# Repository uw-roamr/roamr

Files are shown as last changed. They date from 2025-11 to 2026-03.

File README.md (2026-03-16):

# ROAMR: Really Opensource Autonomous Mobile Robot

Mobile phones and mobile robots have many common requirements:

- performant sensors (cameras, IMUs, LiDAR, GPS) and sensor fusion
- networking capabilities (WiFi, Bluetooth Low Energy, LTE)
- energy efficiency

What if we turned the iPhone into a robot?

## Architecture

### iOS host app:

- exposes the core sensor data through iOS APIs
    - Camera
    - LiDAR (iPhone Pro 12+)
    - IMU
- runs WASM bytecode using statically compiled WAMR iwasm
- communicates with ESP32 over BLE to control motors

### WASM module:

- imports read sensor functions from iOS host
- multi-threaded application with autonomy logic
- compiled using WASI-SDK and threading
    - C++: https://github.com/WebAssembly/wasi-sdk

### ESP32:

- recieves commands over BLE and uses SimpleFOC to control motors

## Setup

```sh
pip install pre-commit
pre-commit
```

## Run App with Robot
- Open/build iOS app.
- Connect to bluetooth using the app
- Drive robot!

### Optional:
- Open HTML page in webpage folder.
- Run websocket on the websocket page of the app
- Connect to app websocket
- Drive robot!

## Development

See [WASM/README.md](WASM/README.md)

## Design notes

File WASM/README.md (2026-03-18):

# WASM Runtime

This directory is the robot runtime that gets compiled to `slam_main.wasm` and hosted by the iOS app through WAMR. The best entrypoint for understanding the system is [WASM/slam_main.cpp](/Users/thomasonzhou/src/roamr/WASM/slam_main.cpp). A mirrored copy also exists at [iOS/roamr/WASM/slam_main.cpp](/Users/thomasonzhou/src/roamr/iOS/roamr/WASM/slam_main.cpp), but the code in this directory should be treated as the source of truth.

Build `slam_main.wasm` from [WASM/build_wasm.sh](/Users/thomasonzhou/src/roamr/WASM/build_wasm.sh):

```sh
cd WASM
./build_wasm.sh
```

The script currently compiles:

- `slam_main.cpp`
- `core/telemetry.cpp`
- `mapping/map.cpp`
- `mapping/map_update.cpp`
- `mapping/visualization.cpp`
- `planning/frontier_explorer.cpp`
- `planning/frontier_simplified.cpp`
- `planning/planner_bridge.cpp`
- `sensors/imu_calibration.cpp`
- `sensors/imu_preintegration.cpp`

Target details:

- `wasm32-wasip1-threads`
- shared memory enabled
- exceptions and RTTI disabled
- output: `slam_main.wasm`

If recording is enabled, the current recorder writes a simple session layout:

```text
session-<timestamp>/
  imu.csv
  pose.csv
  images/
    frame-000001-<timestamp>-<width>x<height>x3.rgb
  points/
    frame-000001-<timestamp>.ply
```

`imu.csv` stores timestamped accelerometer and gyroscope samples. `pose.csv`
stores timestamped predicted poses. Camera images are written as raw RGB with
dimensions encoded in the filename, and point clouds are written as binary PLY
files with per-point RGB colors.

## Host Boundary

The WASM module does not own devices directly. It talks to the iOS host through imported functions and a small exported API.

Imported from the host:

- IMU reads
- LiDAR + camera frame reads
- wheel odometry reads
- motor writes
- telemetry / text logging

Exported to the host:

- `set_planner_goal_map_pixel`
- `clear_planner_goal_map_pixel`

Those exports let the UI set or clear a manual planning target on the rendered map.

## Native ML Bridge

The iOS host now includes a generic model bridge for dynamically loaded perception
models. The intended bundle layout is:

```text
<bundle-dir>/
  stop_sign_main.wasm
  stop_sign_bundle/
    manifest.json
    model.pte
```

Build ML-focused entrypoints with [WASM/build_ml_wasm.sh](/Users/kai/code/roamr/WASM/build_ml_wasm.sh):

```sh
cd WASM
./build_ml_wasm.sh
./build_ml_wasm.sh stop_sign_main.cpp
```

`stop_sign_main.cpp` shows the guest-side pattern:

1. call `ml::open_model("stop_sign_bundle/manifest.json", ...)`
2. poll `ml::run_latest_camera_frame(...)`
3. inspect detections
4. call `write_motors(...)` when policy conditions are met

The manifest contract currently expects:

- `task = "object_detection"`
- `backend = "executorch"`
- first output tensor flattened as rows of 6 floats:
  `class_id, score, x_min, y_min, x_max, y_max`
- RGB input only
- `resize_mode = "stretch"`

See [WASM/ml/model.h](/Users/kai/code/roamr/WASM/ml/model.h),
[WASM/stop_sign_main.cpp](/Users/kai/code/roamr/WASM/stop_sign_main.cpp),
and [WASM/stop_sign_bundle/manifest.json](/Users/kai/code/roamr/WASM/stop_sign_bundle/manifest.json).

## Runtime Overview

`main()` starts seven long-lived threads:

| Thread | Purpose |
| --- | --- |
| `autonomy_thread` | waits for readiness, runs the initial scan, services scan requests |
| `imu_thread` | calibrates IMU biases, integrates orientation, updates the IMU side of `g_pose` |
| `lidar_camera_thread` | reads LiDAR/camera frames into a queued slot buffer and samples pose history for each frame |
| `mapping_thread` | consumes queued LiDAR frames, updates the occupancy map, publishes snapshots and map deltas |
| `planner_thread` | wakes on map/goal changes, computes overlays and world paths |
| `telemetry_thread` | renders map frames plus pose/path/frontier overlays for the host |
| `control_thread` | reads wheel odometry, maintains the shared pose, follows planned paths, drives motors |

This split matters:

- mapping no longer renders the final map image
- planning no longer runs inside the mapping loop
- LiDAR is no longer a two-slot latest-frame handoff

## State Machine

There are two layers of runtime state:

- `g_state`: coarse lifecycle state
- `g_autonomy_substate`: finer autonomy/debug state from [WASM/autonomy/autonomy.h](/Users/thomasonzhou/src/roamr/WASM/autonomy/autonomy.h)

Top-level lifecycle:

```text
SENSOR_INIT -> AUTONOMY_INIT -> AUTONOMY_ENGAGED
```

### `SENSOR_INIT`

The autonomy thread waits for:

- IMU calibration to complete
- at least one non-empty LiDAR frame
- wheel odometry readiness when the selected pose mode depends on wheel odom

### `AUTONOMY_INIT`

The runtime waits for the first real map update, then performs an initial closed-loop `scan_4x90()` if scanning is enabled.

That scan:

- rotates in four quarter-turn segments
- uses wheel/pose feedback, not a blind timed turn
- stops and settles after each segment
- exists to seed the initial occupancy map before normal autonomy begins

### `AUTONOMY_ENGAGED`

Once engaged:

- the planner reacts to map and goal updates
- the control loop follows the latest world-frame path
- failed planning can request another scan
- reaching a goal also requests another scan so new free space can be exposed

Autonomy substates include:

- `PLANNER_INIT`: waiting for planner to initialize from the initial map after scanning 4x90
- `WAITING_FOR_PATH`: planner started and is drawing paths
- `FRONTIER_DETECTION`
- `GOAL_SELECTION`
- `PLANNING_GOAL`
- `FOLLOWING_PATH`
- `NO_PATH_AVAILABLE`
- `SCAN_REQUESTED`
- `SCANNING`: 4x90 loop to refresh local map

## Shared Data Flow

The runtime is built around a few published handoff points rather than one giant loop.

### Pose

`g_pose` is the shared robot pose. It is protected by `m_pose`, and a short pose history buffer is also maintained so LiDAR frames can be associated with a pose near their timestamp.

Current compile-time pose mode in [WASM/slam_main.cpp](/Users/thomasonzhou/src/roamr/WASM/slam_main.cpp) is `fused_IMU_wheel_odom`:

- wheel odometry provides translation
- IMU integration provides the current heading quaternion

That is still a lightweight fusion path, not a full estimator. The code comments correctly note that raw IMU preintegration drifts and should not be treated as a final long-term orientation solution.

### LiDAR / Camera Queue

LiDAR frames move through a four-slot queue:

- slot states: `FREE`, `WRITING`, `QUEUED`, `READING`
- producer: `lidar_camera_thread`
- consumer: `mapping_thread`

For each frame, the producer:

1. claims a free slot
2. reads host LiDAR/camera data
3. converts points into FLU
4. samples pose history at the frame timestamp
5. queues the slot for mapping

This is a real queued producer/consumer pipeline, not the older "latest frame wins" double buffer.

### Mapping Publication

The mapping thread consumes queued LiDAR frames, filters/transforms points, and updates `mapping::Map`.

Each successful update publishes:

- a monotonic `g_map_update_revision`
- `g_latest_map_snapshot`
- `g_latest_map_state`
- a `MapDeltaEvent` with newly occupied cells for the planner

That delta queue is what lets planning skip unnecessary replans when the new obstacle evidence does not intersect the current path corridor.

### Planning Publication

The planner thread wakes on:

- goal changes
- map revisions
- queued map deltas

It reads the latest published snapshot, updates a `PlanningOverlay`, and caches the world-frame path exposed through `planning::bridge::copy_latest_plan_world(...)`.

Two planning modes exist:

- manual goal mode: a UI pixel is converted to a map cell and planned directly
- automatic frontier mode: when no manual goal is active, the planner searches for reachable frontiers

The current bridge logic in [WASM/planning/planner_bridge.cpp](/Users/thomasonzhou/src/roamr/WASM/planning/planner_bridge.cpp):

- keeps a D* Lite planner for direct goal planning
- rate-limits automatic frontier replans
- caches frontier goal candidates across replans
- invalidates the current plan when the controller reaches the goal

### Telemetry

The telemetry thread renders the published map snapshot plus:

- pose trail
- planned path
- frontier candidates
- selected frontier cluster / seed

Rendering happens in [WASM/mapping/visualization.h](/Users/thomasonzhou/src/roamr/WASM/mapping/visualization.h) and its `.cpp`, separate from occupancy integration.

## Subsystem Notes

### Sensors

- [WASM/sensors/calibration.h](/Users/thomasonzhou/src/roamr/WASM/sensors/calibration.h) and [WASM/sensors/imu_calibration.cpp](/Users/thomasonzhou/src/roamr/WASM/sensors/imu_calibration.cpp) handle stillness-based IMU bias estimation and recalibration.
- [WASM/sensors/imu_preintegration.h](/Users/thomasonzhou/src/roamr/WASM/sensors/imu_preintegration.h) and `.cpp` integrate IMU orientation.
- [WASM/sensors/lidar_camera.h](/Users/thomasonzhou/src/roamr/WASM/sensors/lidar_camera.h) defines the host frame payload and point-frame conversion helpers.
- [WASM/sensors/wheel_odometry.h](/Users/thomasonzhou/src/roamr/WASM/sensors/wheel_odometry.h) handles differential-drive odometry integration and wheel-speed estimation.

### Mapping

- [WASM/mapping/map.cpp](/Users/thomasonzhou/src/roamr/WASM/mapping/map.cpp) owns the occupancy grid.
- [WASM/mapping/map_update.h](/Users/thomasonzhou/src/roamr/WASM/mapping/map_update.h) and `.cpp` translate LiDAR frames into map updates and snapshots.
- [WASM/mapping/map_snapshot.h](/Users/thomasonzhou/src/roamr/WASM/mapping/map_snapshot.h) is the planner/telemetry handoff format.
- [WASM/mapping/costmap.h](/Users/thomasonzhou/src/roamr/WASM/mapping/costmap.h) builds the inflated navigation costmap used by planning.

### Planning

- [WASM/planning/planner.h](/Users/thomasonzhou/src/roamr/WASM/planning/planner.h) provides grid planning utilities.
- [WASM/planning/frontier_explorer.cpp](/Users/thomasonzhou/src/roamr/WASM/planning/frontier_explorer.cpp) implements reachable-frontier selection.
- [WASM/planning/planner_bridge.h](/Users/thomasonzhou/src/roamr/WASM/planning/planner_bridge.h) and `.cpp` are the thread boundary between mapping/control/UI.

### Controls

- [WASM/controls/motors.h](/Users/thomasonzhou/src/roamr/WASM/controls/motors.h) converts twist commands to wheel commands and writes motors through the host.
- [WASM/controls/path_following.h](/Users/thomasonzhou/src/roamr/WASM/controls/path_following.h) tracks the published world path and produces velocity commands.

## Current Behavior Summary

If you want the shortest accurate mental model for `slam_main.cpp`, it is this:

1. Bring up IMU, LiDAR, and wheel odometry.
2. Publish a shared pose and short pose history.
3. Queue LiDAR frames with timestamp-matched poses into the mapper.
4. Publish map snapshots and occupancy deltas.
5. Replan only when the map, goal, or current path validity actually changes.
6. Follow the current world path until the goal is reached or planning fails.
7. Trigger another scan when exploration stalls or a goal completes.

## Historical Notes

[WASM/implementation_notes.md](/Users/thomasonzhou/src/roamr/WASM/implementation_notes.md) is still useful for context, but it should be read as design history rather than the current runtime contract. When that file and `slam_main.cpp` disagree, trust `slam_main.cpp`.

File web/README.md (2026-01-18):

# ROAMR Video Streaming

This directory contains the web interface for viewing the live video stream from your ROAMR robot.

## Quick Start

### 1. Start the WebSocket Server on iPhone

1. Open the ROAMR app on your iPhone
2. Navigate to the **WebSocket** tab (bottom navigation)
3. Tap the **Play** button to start the server
4. Note the IP address displayed (e.g., `192.168.1.5`)

### 2. Start Video Streaming

1. Navigate to the **AR View** tab
2. Tap the **Play** button to start the AR session
3. Tap the **Start Stream** button to begin video streaming
   - Button will turn red and say "Stop Stream" when active
   - Video frames are automatically encoded and sent via WebSocket

### 3. View the Stream

1. Open `video-stream.html` in any web browser (Chrome, Safari, Firefox, etc.)
2. Enter the WebSocket URL: `ws://[YOUR_IP]:8080` (e.g., `ws://192.168.1.5:8080`)
3. Click **Connect**
4. You should see the live video stream from your iPhone camera!

## Features

### Video Stream Viewer

- **Real-time video streaming** at 720p, 30 FPS
- **Live statistics**: FPS counter, frame count, and frame size
- **Connection log**: View connection events and debugging info
- **Responsive design**: Works on desktop and mobile browsers
- **Keyboard shortcut**: Press Enter in the URL field to connect

### iOS App Controls

- **Start/Stop Streaming**: Toggle video streaming on/off
- **Quality**: Currently set to 720p at 60% JPEG quality
  - Adjust in `LiDARManager.swift:30` if needed
- **Frame Rate**: 30 FPS (configurable)

## Technical Details

### Architecture

```
iPhone Camera (ARKit)
    ↓
VideoStreamManager (captures & encodes to JPEG)
    ↓
WebSocketServerManager (broadcasts binary data)
    ↓
WebSocket (port 8080)
    ↓
Web Browser (video-stream.html)
```

### Performance

- **Resolution**: 1280x720 (720p)
- **Frame Rate**: ~30 FPS
- **Compression**: JPEG at 60% quality
- **Bandwidth**: ~1-2 Mbps (depends on scene complexity)
- **Latency**: ~100-300ms end-to-end

### Customization

To adjust video quality, edit `iOS/roamr/Managers/LiDARManager.swift`:

```swift
videoStreamManager.configure(
    arSession: session,
    targetFPS: 30,      // Frames per second
    quality: 0.6        // JPEG quality (0.0 - 1.0)
)
```

To change resolution, edit `iOS/roamr/Managers/VideoStreamManager.swift`:

```swift
private var targetWidth: Int = 1280   // Width in pixels
private var targetHeight: Int = 720   // Height in pixels
```

## Troubleshooting

### Connection Issues

- **Can't connect**: Ensure both devices are on the same WiFi network
- **Firewall**: Some networks block WebSocket connections
- **IP address**: Double-check the IP address from the iOS app

### Performance Issues

- **Low FPS**: Reduce quality or resolution in settings
- **High latency**: Check network quality, reduce bandwidth usage
- **Choppy video**: Ensure iPhone isn't overheating or low on battery

### No Video Stream

1. Ensure WebSocket server is running (green indicator)
2. Check that AR session is active (LiDAR tab)
3. Verify "Start Stream" button is pressed (should be red)
4. Check browser console for errors (F12)

## Requirements

- **iOS Device**: iPhone with ARKit support (iPhone 6s or later)
- **Network**: Both devices on same WiFi network
- **Browser**: Any modern browser (Chrome, Safari, Firefox, Edge)

## Advanced Usage

### URL Parameters

You can pre-populate the WebSocket URL using query parameters:

```
video-stream.html?ip=192.168.1.5
```

This will automatically set the URL to `ws://192.168.1.5:8080`.

### Integration with Robot Control

The video stream runs alongside the existing WebSocket functionality for robot control. You can:
- Send control commands via WebSocket (text messages)
- Receive video stream (binary frames)
- Forward commands to Bluetooth peripheral (ESP32)

All on the same WebSocket connection!

## Future Enhancements

Potential improvements:
- H.264 encoding for better compression
- WebRTC for lower latency
- Multiple video quality presets
- Recording capability
- Multi-client streaming with individual quality settings

---

**Built for ROAMR** - Really Opensource Autonomous Mobile Robot

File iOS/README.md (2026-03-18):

# iOS App

## Getting started

1. [Enable developer mode on iPhone](https://developer.apple.com/documentation/xcode/enabling-developer-mode-on-a-device)

2. Under the `Signing & Capabilities` tab in XCode, select a team (e.g. Personal Team) and enter a unique identifier.

3. Click Build.

Core components:

## ExecuTorch

The dynamic model bridge in `Managers/ModelRunner.swift` is written to use the
official ExecuTorch Swift package when it is linked into the app. Until that
package is added in Xcode, `ml_open_model` will return `runtime_unavailable`.

## How build new WAMR
- Clone WAMR (https://github.com/bytecodealliance/wasm-micro-runtime)
- Navigate to `/wasm-micro-runtime/product-mini/platforms`
- Run `generate_xcodeproj.sh`
- Open the XCode project and edit the `CMakeList.txt` file to be the same as the one provided in our repo.
- Run the `ALL_BUILD` target
- Open the header files, located at `/wasm-micro-runtime/product-mini/platforms/ios/iwasm-proj/distribution/wasm`
- Copy them to your project and include them in a header bridging file
- Copy the library (.a file) to your project, located at `/wasm-micro-runtime/product-mini/platforms/ios/iwasm-proj`
- Check this `library.a` file is added to `Link Binaries with Libraries` inside `Build Phases`
- Add the folder `library.a` lives in to `Library Search Paths` inside `Build Settings`

## WebAssembly Runner

- [WAMR: WebAssemby Micro Runtime](https://bytecodealliance.github.io/wamr.dev/)

## Sensor Access

- Managers/LiDARManager.swift

## TODO:

- Protobuf serialization/deserialization
- Connect sensors to WASM

- manage different PRODUCT_BUNDLE_IDENTIFIER under project.pbxproj

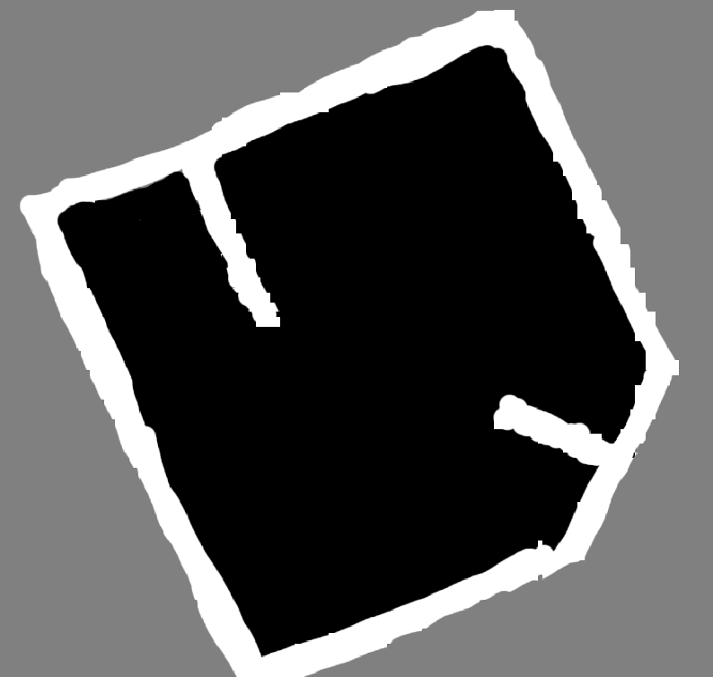
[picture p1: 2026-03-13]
tools/gt3.png

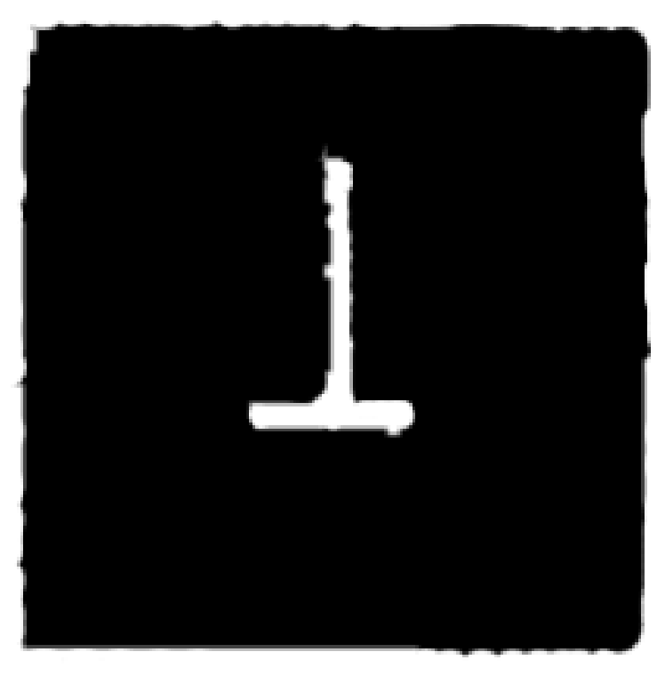
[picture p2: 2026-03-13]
tools/gt2.png

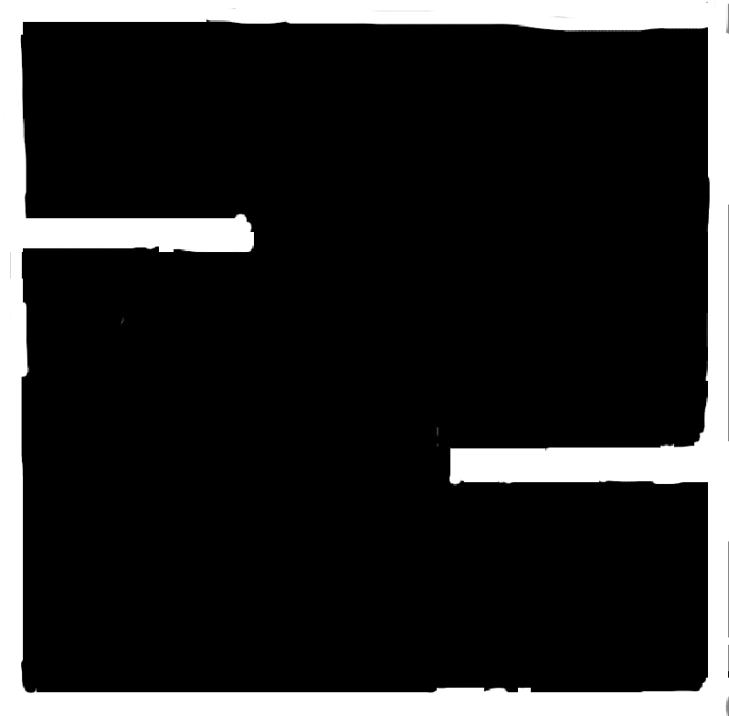
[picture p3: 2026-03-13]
tools/gt1.png

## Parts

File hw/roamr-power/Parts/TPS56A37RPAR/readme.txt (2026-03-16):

Notes:

1. All drill sizes are the maximum size provided by the manufacture (as required to calculate the minimum pad size).
2. All dimensions in building footprints are the maximum (including any tolerance) as defined by the manufacturer with the exception of row pitch (which is always nominal).  If only the normal sizing is provided we will input that dimension in mils, rounded to the nearest mil per our standards.
3. Slots are currently identified as entities describing the size of the slot (arcs, lines, etc.) on the board outline layer.  The extremities are identified with a via at each end.  These slots will either need to be:
	a. identified and dimensioned on your fabrication document
	b. or they will need to be converted to slots (assuming the targeted tool has a slot capability) using the process defined in your cad tool for identifying a padstack as a slot.
		i. Typically this is only capable of a width and length of the slot and a size of the mill radius that creates the slot.
		ii. Choosing to use the native tool slots will require removing entities on the board outline and the associated pads in the footprint.

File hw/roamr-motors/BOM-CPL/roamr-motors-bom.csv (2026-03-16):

Reference | Qty | Value | Manufacturer_Part_Number | DNP | Exclude from BOM | Exclude from Board | Footprint | Datasheet
C1,C2,C8 | 3 | 10uF |  |  |  |  | Capacitor_SMD:C_0603_1608Metric | ~
C3,C4 | 2 | 2.2uF |  |  |  |  | Capacitor_SMD:C_0603_1608Metric | ~
C5 | 1 | 4.7uF |  |  |  |  | Capacitor_SMD:C_0603_1608Metric | ~
C6,C9,C14,C17,C23,C26 | 6 | 0.1uF |  |  |  |  | Capacitor_SMD:C_0603_1608Metric | ~
C7 | 1 | 22uF |  |  |  |  | Capacitor_SMD:C_0603_1608Metric | ~
C10,C13,C16,C22,C25 | 5 | 1uF |  |  |  |  | Capacitor_SMD:C_0603_1608Metric | ~
C11,C12 | 2 | 0.1uF |  | DNP |  |  | Capacitor_SMD:C_0603_1608Metric | ~
C15,C24 | 2 | 47nF |  |  |  |  | Capacitor_SMD:C_0603_1608Metric | ~
C18,C20,C21,C27,C29,C30 | 6 | 30pF |  |  |  |  | Capacitor_SMD:C_0603_1608Metric | ~
C19,C28 | 2 | 10uF |  |  |  |  | RVT1E100M0405:RVT1E100M0405 | ~
D1,D4 | 2 | SMLJ13CA-R | SMLJ13CA-R |  |  |  | SMLJ13CA-R:DIOM7959X262N | ~
D2,D3,D5,D6,D7,D8 | 6 | LESD5D5.0CT1G | LESD5D5.0CT1G |  |  |  | LESD5D5.0CT1G:LESD5D50CT1G | ~
D9,D10 | 2 | 1N5819HW-7-F | 1N5819HW-7-F |  |  |  | 1N5819HW_7_F:SOD3715X145N
D11,D12,D17,D18 | 4 | PMEG3050EP,115 | PMEG3050EP,115 |  |  |  | PMEG3050EP:PMEG3050EP115 | https://assets.nexperia.com/documents/data-sheet/PMEG3050EP.pdf
D13,D14,D15,D16 | 4 | GLED | KT-0603G |  |  |  | KT-0603:LEDC1608X70N | ~
D19 | 1 | RLED | KT-0603R |  |  |  | KT-0603:LEDC1608X70N | ~
F1,F2 | 2 | 0466005.NRHF | 0466005.NRHF |  |  |  | 0466005:F1206 | https://lcsc.com/product-detail/Surface-Mount-Fuses_Littelfuse_0466005-NRHF_5A-32V_C57525.html
J1,J4,J5,J8 | 4 | JST_XH_S2B-XH-A-1 | JST_XH_S2B-XH-A-1 |  |  |  | Connector_JST:JST_XH_S2B-XH-A-1_1x02_P2.50mm_Horizontal | ~
J2,J3 | 2 | USB4215-03-A | USB4215-03-A |  |  |  | USB4215_03_A:CONN_8p94X6p5X3p16_12L_GCC | USB4215-03-A
J6,J9 | 2 | JST_PH_B3B-PH-SM4-TB | JST_PH_B3B-PH-SM4-TB |  |  |  | Connector_JST:JST_PH_B3B-PH-SM4-TB_1x03-1MP_P2.00mm_Vertical | ~
J7,J10 | 2 | JST_SH_BM06B-SRSS-TB | JST_SH_BM06B-SRSS-TB |  |  |  | Connector_JST:JST_SH_BM06B-SRSS-TB_1x06-1MP_P1.00mm_Vertical | ~
NT1,NT2 | 2 | NetTie_2 |  |  | Excluded from BOM |  | NetTie:NetTie-2_SMD_Pad0.5mm | ~
Q1,Q2 | 2 | L8050QLT1G | L8050QLT1G |  |  |  | L8050QLT1G:L8050QLT1G | https://datasheet.datasheetarchive.com/originals/distributors/Datasheets-28/DSA-558356.pdf
R1,R2,R3,R4 | 4 | 5.1kR |  |  |  |  | Resistor_SMD:R_0603_1608Metric | ~
R5 | 1 | 4.3kR |  |  |  |  | Resistor_SMD:R_0603_1608Metric | ~
R6 | 1 | 910R |  |  |  |  | Resistor_SMD:R_0603_1608Metric | ~
R7,R16,R17 | 3 | 0R |  |  |  |  | Resistor_SMD:R_0603_1608Metric | ~
R8,R9 | 2 | 100R |  |  |  |  | Resistor_SMD:R_0603_1608Metric | ~
R10 | 1 | 47.5k |  | DNP |  |  | Resistor_SMD:R_0603_1608Metric | ~
R11 | 1 | 1k |  |  |  |  | Resistor_SMD:R_0603_1608Metric | ~
R12,R13,R19 | 3 | 10kR |  |  |  |  | Resistor_SMD:R_0603_1608Metric | ~
R14 | 1 | 22.1k |  |  |  |  | Resistor_SMD:R_0603_1608Metric | ~
R15 | 1 | 47.5k |  |  |  |  | Resistor_SMD:R_0603_1608Metric | ~
R18 | 1 | 430R |  |  |  |  | Resistor_SMD:R_0603_1608Metric | ~
R20,R21,R22,R23,R24,R25 | 6 | 1kR |  |  |  |  | Resistor_SMD:R_0603_1608Metric | ~
SW1,SW2 | 2 | 1825910-6 | 1825910-6 |  |  |  | 1825910_6:SW4_1825910-B_TEC | 1825910-6
TP1,TP2,TP3,TP4,TP6,TP7,TP8,TP9,TP10,TP11,TP12 | 11 | TestPoint |  |  |  |  | TestPoint:TestPoint_Pad_D1.5mm | ~
TP5 | 1 | TestPoint | 5005-5009 |  |  |  | TestPoint:TestPoint_Keystone_5005-5009_Compact | ~
U1 | 1 | SGM2212-3.3XKC3G_TR | SGM2212-3.3XKC3G/TR |  |  |  | SGM2212-3.3XKC3G_TR:SOT230P700X180-4N | http://cn.sg-micro.com/uploads/soft/20220506/1651835177.pdf
U2 | 1 | CP2102N-A02-GQFN28 | CP2102N-A02-GQFN28 |  |  |  | Package_DFN_QFN:QFN-28-1EP_5x5mm_P0.5mm_EP3.35x3.35mm | https://www.silabs.com/documents/public/data-sheets/cp2102n-datasheet.pdf
U3 | 1 | ESP32-S3-WROOM-1 | ESP32-S3-WROOM-1 |  |  |  | RF_Module:ESP32-S3-WROOM-1 | https://www.espressif.com/sites/default/files/documentation/esp32-s3-wroom-1_wroom-1u_datasheet_en.pdf
U4,U5 | 2 | DRV8316CRRGFR | DRV8316CRRGFR |  |  |  | DRV8316CRRGFR:VQFN40_RGF_TEX | https://www.ti.com/lit/gpn/drv8316c

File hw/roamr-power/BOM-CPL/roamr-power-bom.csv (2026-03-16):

Id | Designator | Footprint | Quantity | Designation | Supplier and ref
1 | D6 | DIOM7959X262N | 1 | SMLJ13A
2 | C6 | C_0805_2012Metric | 1 | 15.0uF
3 | D8,D7,D2 | LEDC1608X70N | 3 | GLED
4 | D3 | LEDC1608X70N | 1 | RLED
5 | R16,R15 | R_0603_1608Metric | 2 | 56kR
6 | J4 | USB4125GFA | 1 | USB4125-GF-A
7 | J3,J2 | JST_XH_S2B-XH-A-1_1x02_P2.50mm_Horizontal | 2 | JST_XH_S2B-XH-A-1
8 | Q1 | SOT95P240X110-3N | 1 | BSS84PH6327XTSA2
9 | U2 | SOT95P280X145-6N | 1 | TPS2553DDBVR
10 | R6 | R_0603_1608Metric | 1 | 1.3R
11 | R8,R11 | R_0603_1608Metric | 2 | 510R
12 | R10,R7 | R_0603_1608Metric | 2 | 910R
13 | C9,C7 | C_0603_1608Metric | 2 | 4.7uF
14 | R12,R13 | R_0603_1608Metric | 2 | 10kR
15 | SW2,SW1 | OS102011MA1QN1 | 2 | OS102011MS2QN1
16 | C1,C14,C13 | C_0603_1608Metric | 3 | 0.1uF
17 | L2 | IND_VLS6045EX-4R7M_TDK | 1 | 4.7uH
18 | L1 | IND_PCC-M0645M_PAN-L | 1 | 3.3uH
19 | U1 | RPA0010A-MFG | 1 | TPS56A37RPAR
20 | C5 | C_0603_1608Metric | 1 | 1.0uF
21 | C10,C4 | C_0603_1608Metric | 2 | 22.0uF
22 | C8,C11 | 16SVF270M | 2 | 39.0uF
23 | D1,D5,D4 | PMEG3050EP115 | 3 | PMEG3050EP,115
24 | J1 | TB00250002BE | 1 | TB002-500-02BE
25 | C12 | CAPAE660X610N | 1 | 120uF
26 | R4 | R_0603_1608Metric | 1 | 10.0kR
27 | TP1,TP4,TP2 | TestPoint_Pad_D1.5mm | 3 | TestPoint
28 | R5 | R_0603_1608Metric | 1 | 4.3kR
29 | C3 | C_0603_1608Metric | 1 | 150.0pF
30 | R14 | R_0603_1608Metric | 1 | 7.5kR
31 | TP3 | TestPoint_Keystone_5005-5009_Compact | 1 | TestPoint
32 | R9 | R_0603_1608Metric | 1 | 100kR
33 | U3 | SON50P200X200X80-9N | 1 | TPS259541DSGR
34 | R2 | R_0603_1608Metric | 1 | 24kR
35 | R1 | R_0603_1608Metric | 1 | 52.3kR
36 | R3 | R_0603_1608Metric | 1 | 73.2kR

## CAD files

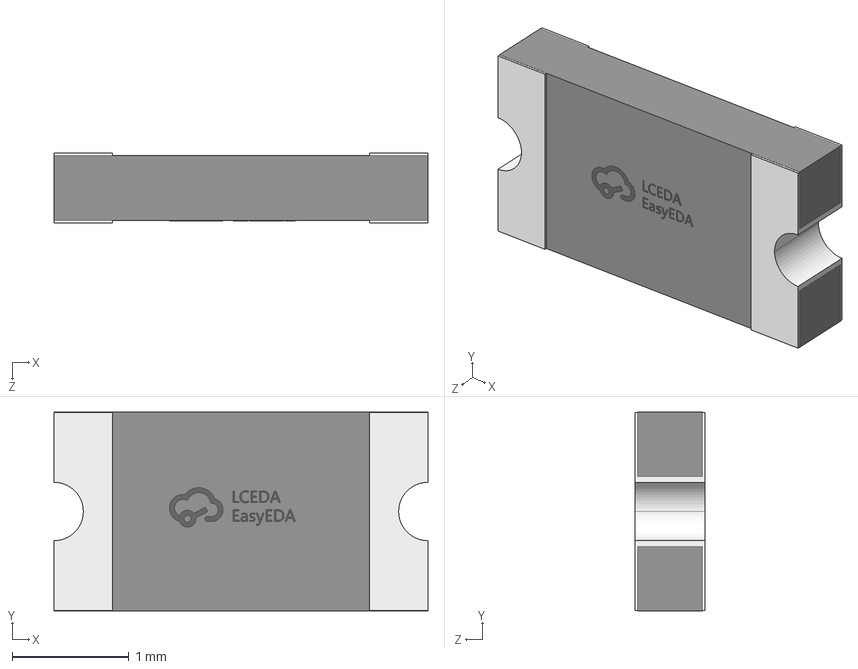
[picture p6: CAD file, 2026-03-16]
hw/roamr-motors/Parts/0466005/F1206_L3.2-W1.7-H0.6.step
3.20 x 1.70 x 0.6 mm

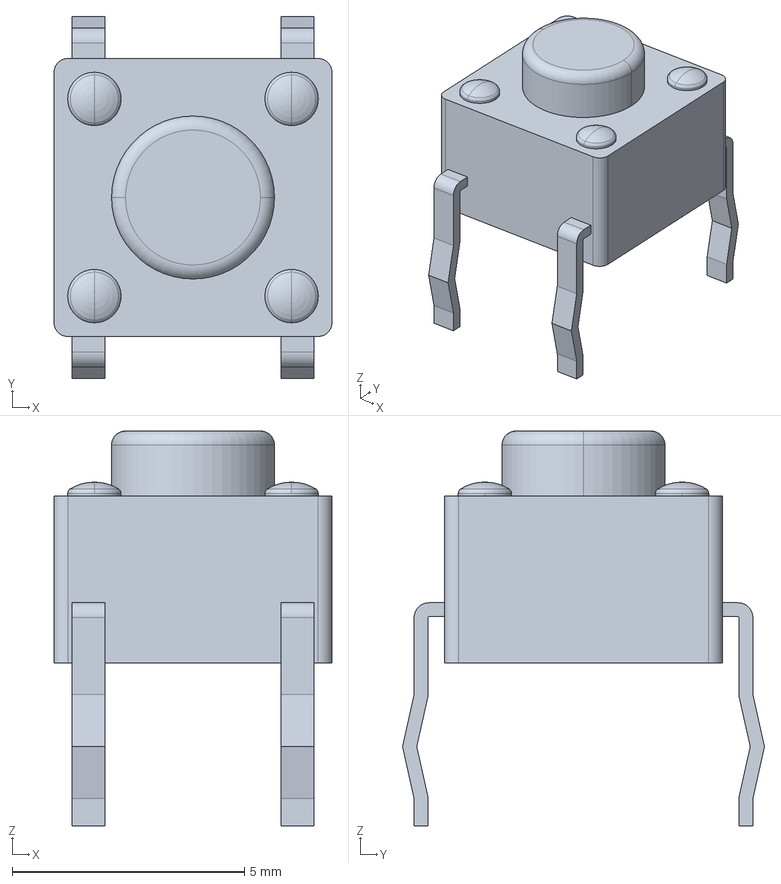
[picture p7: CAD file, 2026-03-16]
hw/roamr-motors/Parts/1825910_6/c-1825910-6-c-3d.stp
5.99 x 7.80 x 8.51 mm

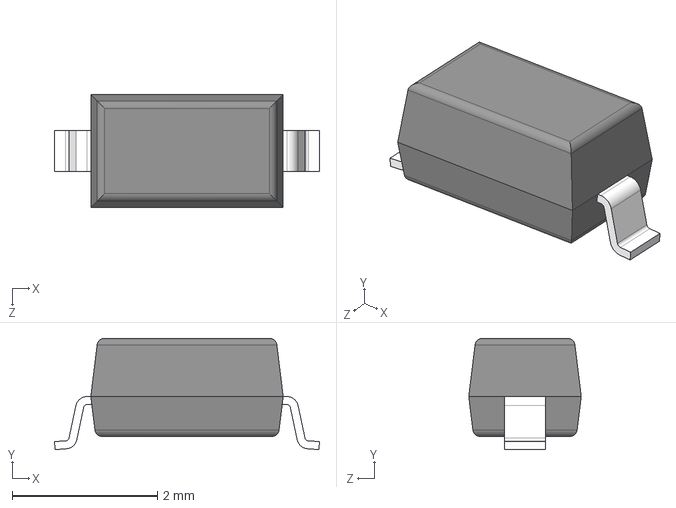
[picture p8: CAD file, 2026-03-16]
hw/roamr-motors/Parts/1N5819HW_7_F/1N5819HW-7-F.step
3.65 x 1.53 x 1.55 mm

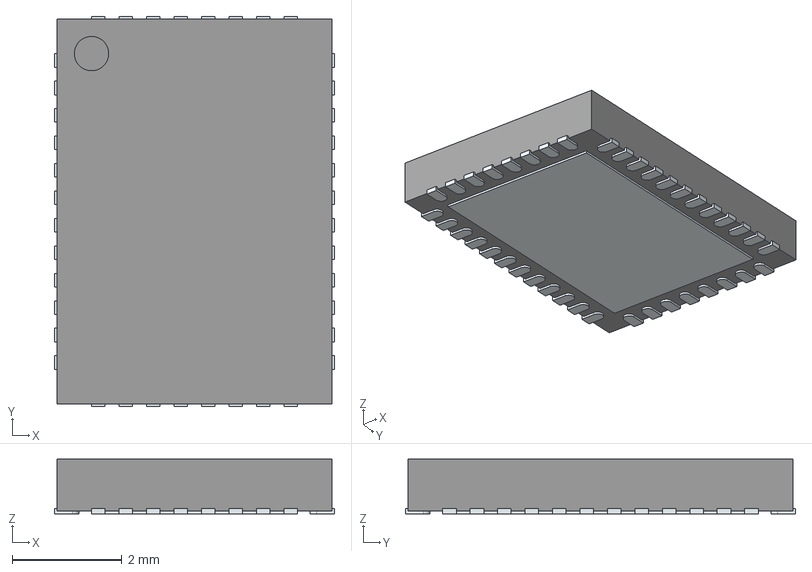
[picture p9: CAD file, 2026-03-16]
hw/roamr-motors/Parts/DRV8316CRRGFR/DRV8316CRRGFR.stp
5.10 x 7.10 x 1.00 mm
ThermalPin
PinsArrayLR
PinsArrayTB

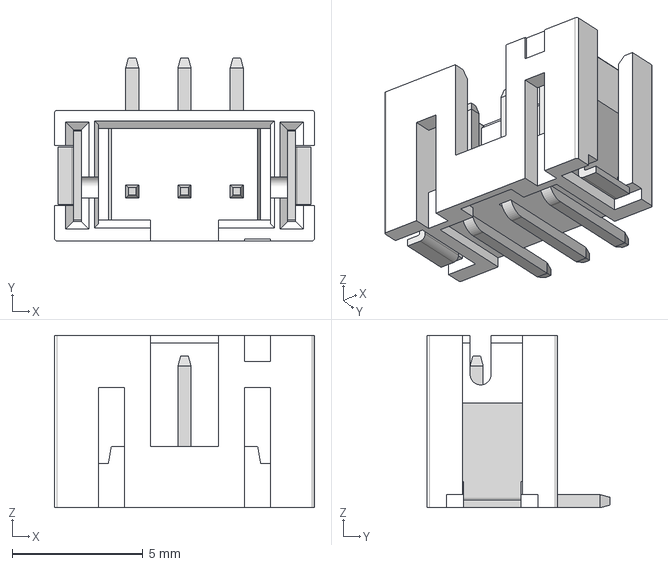
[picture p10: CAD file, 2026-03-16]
hw/roamr-motors/Parts/JST-B3B-PH-SM4-TB/B3B-PH-SM4-TB_LF__SN_.stp
9.95 x 7.00 x 6.60 mm

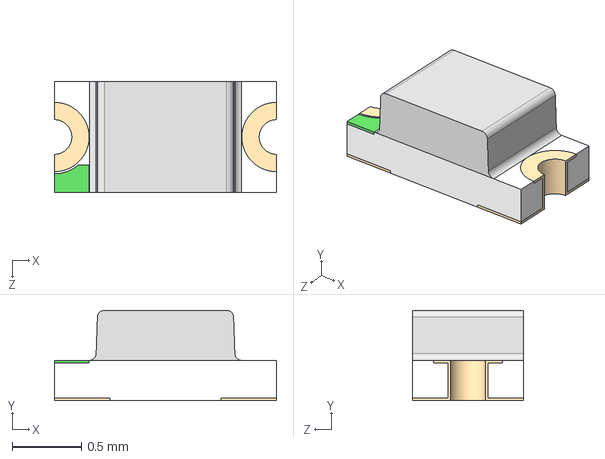
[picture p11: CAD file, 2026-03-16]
hw/roamr-motors/Parts/KT-0603/KT-0603R--3DModel-STEP-269445.STEP
1.60 x 0.65 x 0.8 mm

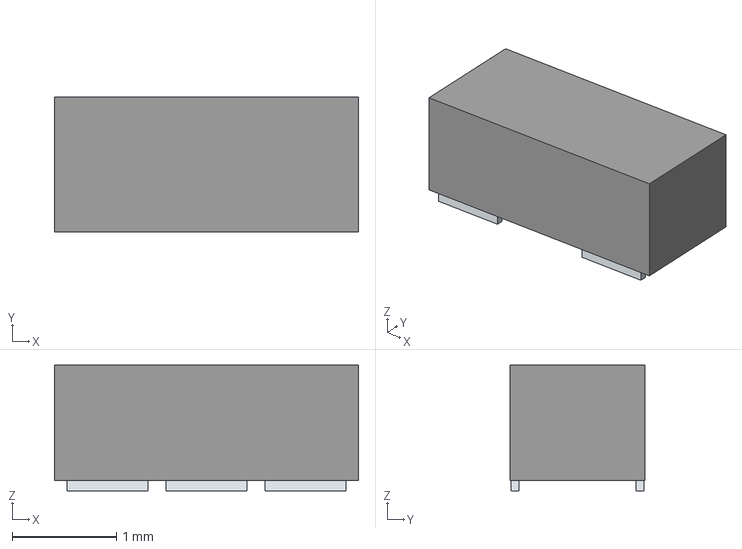
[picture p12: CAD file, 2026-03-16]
hw/roamr-motors/Parts/L8050QLT1G/L8050QLT1G.stp
2.92 x 1.30 x 1.21 mm
Pins

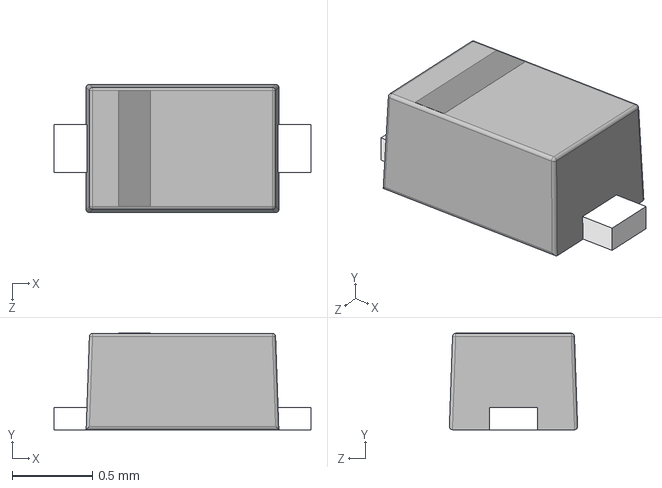
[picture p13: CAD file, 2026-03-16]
hw/roamr-motors/Parts/LESD5D5.0CT1G/LESD5D5.0CT1G.stp
1.60 x 0.601 x 0.799 mm

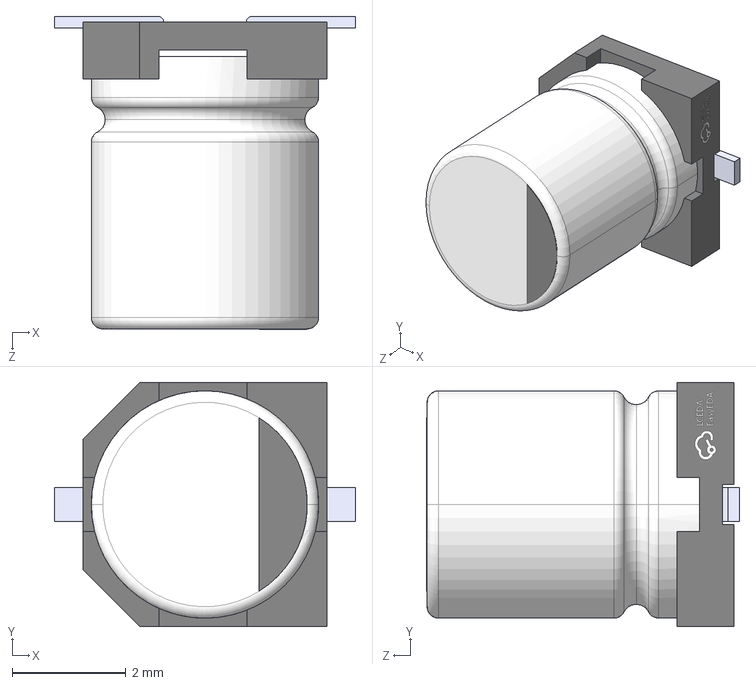
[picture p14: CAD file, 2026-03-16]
hw/roamr-motors/Parts/RVT1E100M0405/CAP-SMD_L4.3-W4.3-H5.3-LS5.1.step
5.30 x 4.30 x 5.51 mm

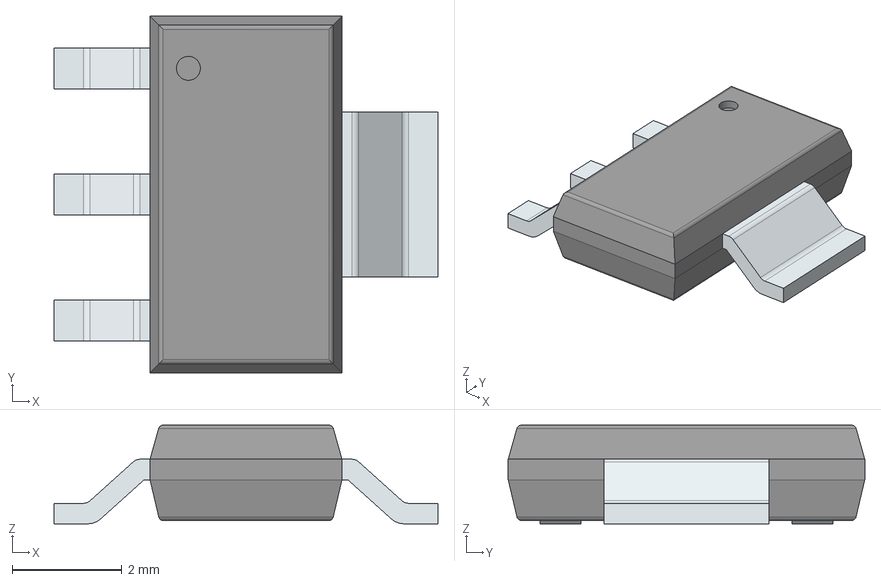
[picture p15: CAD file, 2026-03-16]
hw/roamr-motors/Parts/SGM2212-3.3XKC3G_TR/SGM2212-3.3XKC3G_TR.stp
7.00 x 6.50 x 1.80 mm
PinsArrayL
FilletPinR

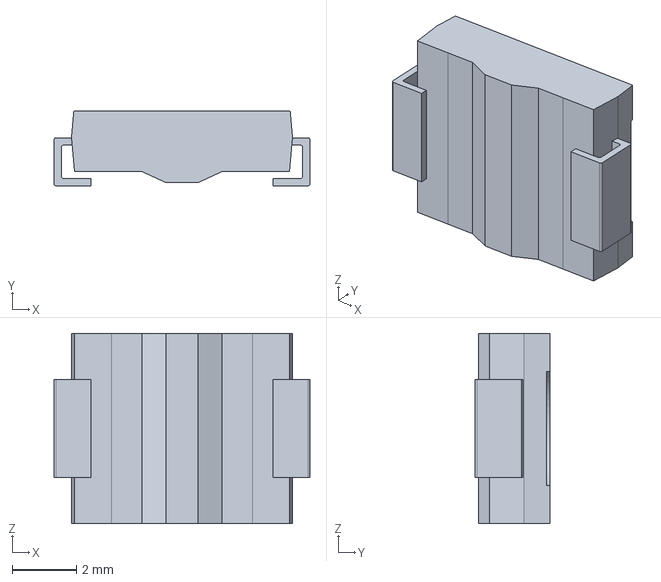
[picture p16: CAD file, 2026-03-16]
hw/roamr-motors/Parts/SMLJ13CA-R/SMLJ13CA-R.stp
7.94 x 2.31 x 5.91 mm

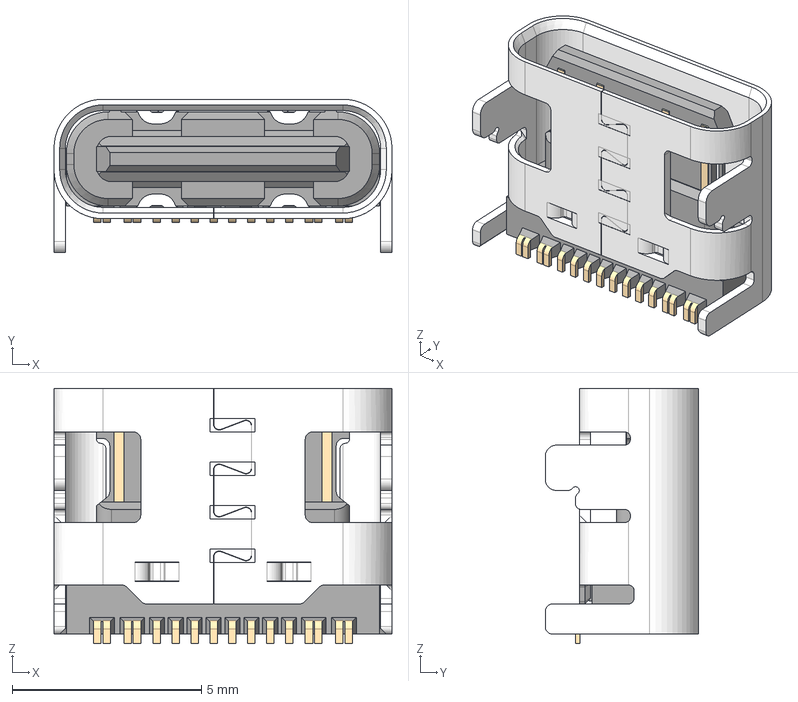
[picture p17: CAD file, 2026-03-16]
hw/roamr-motors/Parts/USB4215_03_A/USB4215-03-A.stp
8.94 x 4.06 x 6.75 mm
USB4215-03-A_PART1
USB4215-03-A_PART2

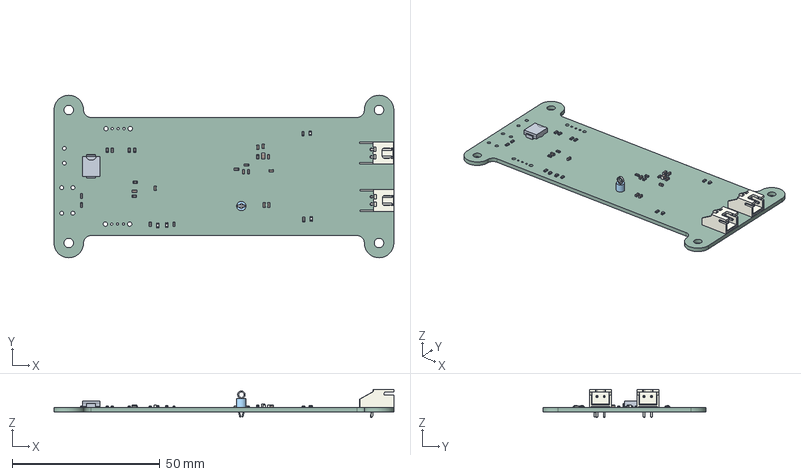
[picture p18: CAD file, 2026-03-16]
hw/roamr-power/Outputs/roamr-power.step
115.0 x 55.0 x 9.50 mm
KT-0603R--3DModel-STEP-269445 x 4
R_0603_1608Metric x 16
SMLJ13CA-R
C_0603_1608Metric x 9
JST_XH_S2B-XH-A-1_1x02_P2.50mm_Horizontal x 2
C_0805_2012Metric
TestPoint_Keystone_5005-5009_Compact
roamr-power_PCB

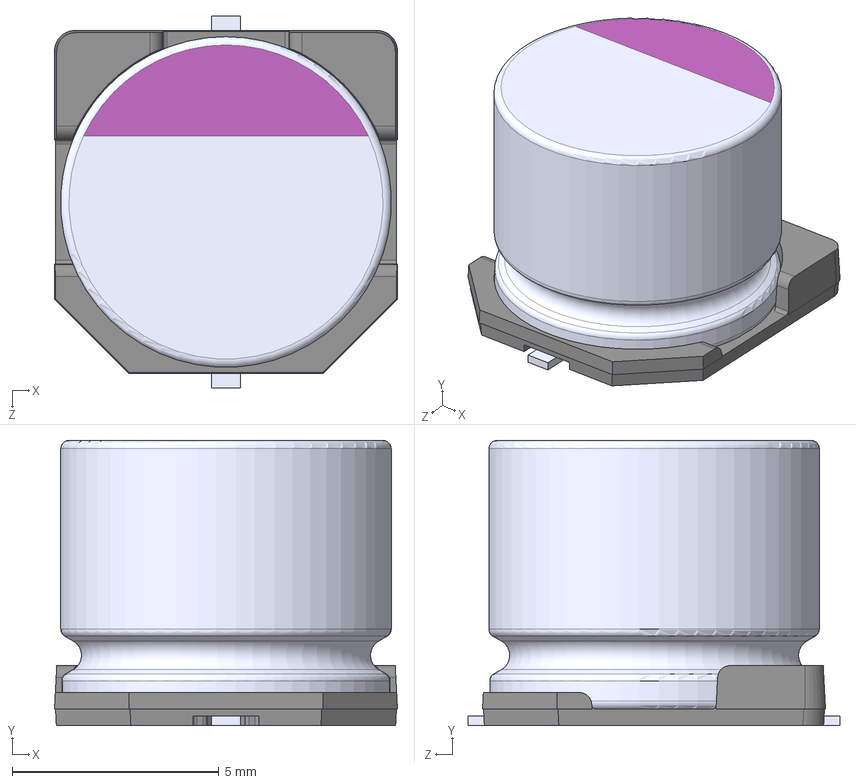
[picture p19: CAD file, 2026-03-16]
hw/roamr-power/Parts/35SVPF39M/35SVPF39M.stp
8.30 x 6.90 x 9.00 mm

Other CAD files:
hw/roamr-power/Parts/BSS84PH6327XTSA2/BSS84PH6327XTSA2.stp
hw/roamr-power/Parts/ETQ-P4M3R3YFN/ETQ-P4M3R3YFN.stp
hw/roamr-power/Parts/GYG1E121MCQ1GS/GYG1E121MCQ1GS.stp
hw/roamr-power/Parts/PMEG3050EP/PMEG3050EP,115.stp
hw/roamr-power/Parts/OS102011MS2QN1/OS102011MS2QN1.stp
hw/roamr-power/Parts/TB002-500-02BE/TB002-500-02BE.stp
hw/roamr-power/Parts/TPS2553DDBVR/TPS2553DDBVR.stp
hw/roamr-power/Parts/TPS259541DSGR/TPS259541DSGR.stp
hw/roamr-power/Parts/TPS56A37RPAR/TPS56A37RPAR.stp
hw/roamr-power/Parts/USB4125-GF-A/USB4125-GF-A.stp
hw/roamr-power/Parts/VLS6045EX_4R7M/VLS6045EX-4R7M.stp

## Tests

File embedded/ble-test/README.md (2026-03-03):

| Supported Targets | ESP32 | ESP32-C2 | ESP32-C3 | ESP32-C5 | ESP32-C6 | ESP32-C61 | ESP32-H2 | ESP32-H21 | ESP32-P4 | ESP32-S2 | ESP32-S3 |
| --- | ----- | --- | --- | --- | --- | --- | --- | --- | --- | --- | --- |

# BLE Test Example

This folder structure was derived from the [esp-idf](https://github.com/espressif/esp-idf) 'blink' example.

This provides a demo which advertises the esp32 as "ESP32C6". You can download the nrfConnect app on your phone to connect to the device and upload data. Currently, the device only supports receiving and printing strings.

## How to Use Example

Before project configuration and build, be sure to set the correct chip target using `idf.py set-target <chip_name>`. If using vscode, you can also set the target in the bottom bar where you see a chip symbol.

### Hardware Required

* A development board with BLE compatibility (e.g. ESP32-C6-DevKitC etc.)
* A USB cable for Power supply and programming

See [Development Boards](https://www.espressif.com/en/products/devkits) for more information about it.

### Configure the Project

Open the project configuration menu (`idf.py menuconfig`). Or you can click the gear symbol in the bottom menu of vscode.

Make sure to select BLE 4.2 and disable BLE 5.

### Build and Flash

Run `idf.py -p PORT flash monitor` to build, flash and monitor the project. Or, you can click the wrench icon to build the project, then the lightning icon to flash the project.

(To exit the serial monitor, type ``Ctrl-]``.)

See the [Getting Started Guide](https://docs.espressif.com/projects/esp-idf/en/latest/get-started/index.html) for full steps to configure and use ESP-IDF to build projects.

### Monitor the Output

Run `idf.py monitor` to monitor the project. Or, you can the TV icon to monitor the serial output from the ESP32.

## SimpleFOC

SimpleFOC and SimpleFOC drivers are cloned into components.

Setup details (clone commands + required component `CMakeLists.txt` files):
[`SIMPLEFOC_COMPONENTS_SETUP.md`](SIMPLEFOC_COMPONENTS_SETUP.md)

# SimpleFOC Components Setup

This project expects `simplefoc` and `simplefoc_drivers` as local ESP-IDF components under `components/`.

## 1. Clone Repositories

From the project root:

```bash
mkdir -p components
git clone https://github.com/simplefoc/Arduino-FOC.git components/simplefoc
git clone https://github.com/simplefoc/Arduino-FOC-drivers.git components/simplefoc_drivers
```

Optional: pin to known-good revisions:

```bash
git -C components/simplefoc checkout 395b6cd4c621fe460c1d61a99bc0fc38913d5481
git -C components/simplefoc_drivers checkout ed05aa1644de36cbd19f43e8ea5c3edb643cefa9
```

## 2. Add `CMakeLists.txt` Files

Upstream repos do not include ESP-IDF component registration files, so create them.

### `components/simplefoc/CMakeLists.txt`

```cmake
file(GLOB_RECURSE SOURCES "src/*.cpp" "src/*.c")

idf_component_register(SRCS ${SOURCES}
                       INCLUDE_DIRS "src"
                       REQUIRES espressif__arduino-esp32)

target_compile_options(${COMPONENT_LIB} PRIVATE
                       -Wno-error=uninitialized
                       -Wno-error=overloaded-virtual
                       -Wno-error=switch
                       -Wno-error=comment)
```

### `components/simplefoc_drivers/CMakeLists.txt`

```cmake
file(GLOB_RECURSE SOURCES "src/*.cpp" "src/*.c")

idf_component_register(SRCS ${SOURCES}
                       INCLUDE_DIRS "src"
                       REQUIRES espressif__arduino-esp32 simplefoc)

target_compile_options(${COMPONENT_LIB} PRIVATE
                       -Wno-error=overloaded-virtual
                       -Wno-error=switch
                       -Wno-error=comment)
```

## 3. Confirm Main Component Dependencies

Ensure [`main/CMakeLists.txt`](main/CMakeLists.txt) includes:

- `REQUIRES ... simplefoc ... simplefoc_drivers`

Then build:

```bash
idf.py build
```

## BLE Odometry Upload Protocol

The firmware exposes one custom service (`0x00FF`) with 2 characteristics:

- `0xFF01` control (`WRITE`, `WRITE_NO_RSP`)
- `0xFF02` data (`NOTIFY`)

### Control commands (`FF01`)

- `SET_PERIOD <sample_period_ms>`
- `CLEAR` (clears pending encoder backlog)

Legacy motor command writes (`"<left> <right> <duration>"`) still work on `FF01` and can be sent continuously while odometry notifications are active.

### Data frames (`FF02` notify)

Each notification is MTU-aware and chunked (`max_payload = ATT_MTU - 3`).

- Header:
- `seq`: `uint16` little-endian
- `n`: `uint8` sample count
- Payload:
- `n` samples, each sample:
- `dl_ticks`: `int16` little-endian
- `dr_ticks`: `int16` little-endian

So frame size is `3 + 4*n` bytes.

There is no separate status characteristic in the stripped-down firmware.
### Status payload (`FF03` read, little-endian)

- `state`: `uint8` (`0=IDLE, 1=RECORDING, 2=UPLOADING`)
- `buffered_samples`: `uint16`
- `dropped_samples`: `uint16`
- `last_seq`: `uint16` (`0xFFFF` before first upload frame)
- `sample_period_ms`: `uint16`

### docker build

For reproducible builds across platforms, we suggest using the docker container for release-v5.5

https://docs.espressif.com/projects/esp-idf/en/stable/esp32/api-guides/tools/idf-docker-image.html

```sh
docker run --rm -v $PWD:/project -w /project -u $UID -e HOME=/tmp -it espressif/idf:release-v5.5
```

## Linux
```sh
docker run --rm -v $PWD:/project -w /project -u $UID -e HOME=/tmp -it --device=/dev/ttyUSB0 --group-add dialout espressif/idf:release-v5.5
```

Build, then flash the firmware.

```sh
idf.py build
```

Then flash the ESP. It may be necessary to configure additional settings in Windows or MacOS.

```sh
idf.py flash
```

## Windows Instructions:

Run the following command in a separate terminal to open the COM port to the ESP (check your COM port in device manager)
```sh
esp_rfc2217_server -v -p 4000 COM3
```
To flash the ESP,  run the following command in roamr/embedded/ble-test
```sh
MSYS_NO_PATHCONV=1 docker run --rm -v "/$(pwd):/project" -w /project -u $UID -e HOME=/tmp -it espressif/idf:release-v5.5 idf.py --port 'rfc2217://host.docker.internal:4000?ign_set_control' flash
```

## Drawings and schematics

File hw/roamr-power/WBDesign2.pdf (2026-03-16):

## WEBENCH ® Design Report

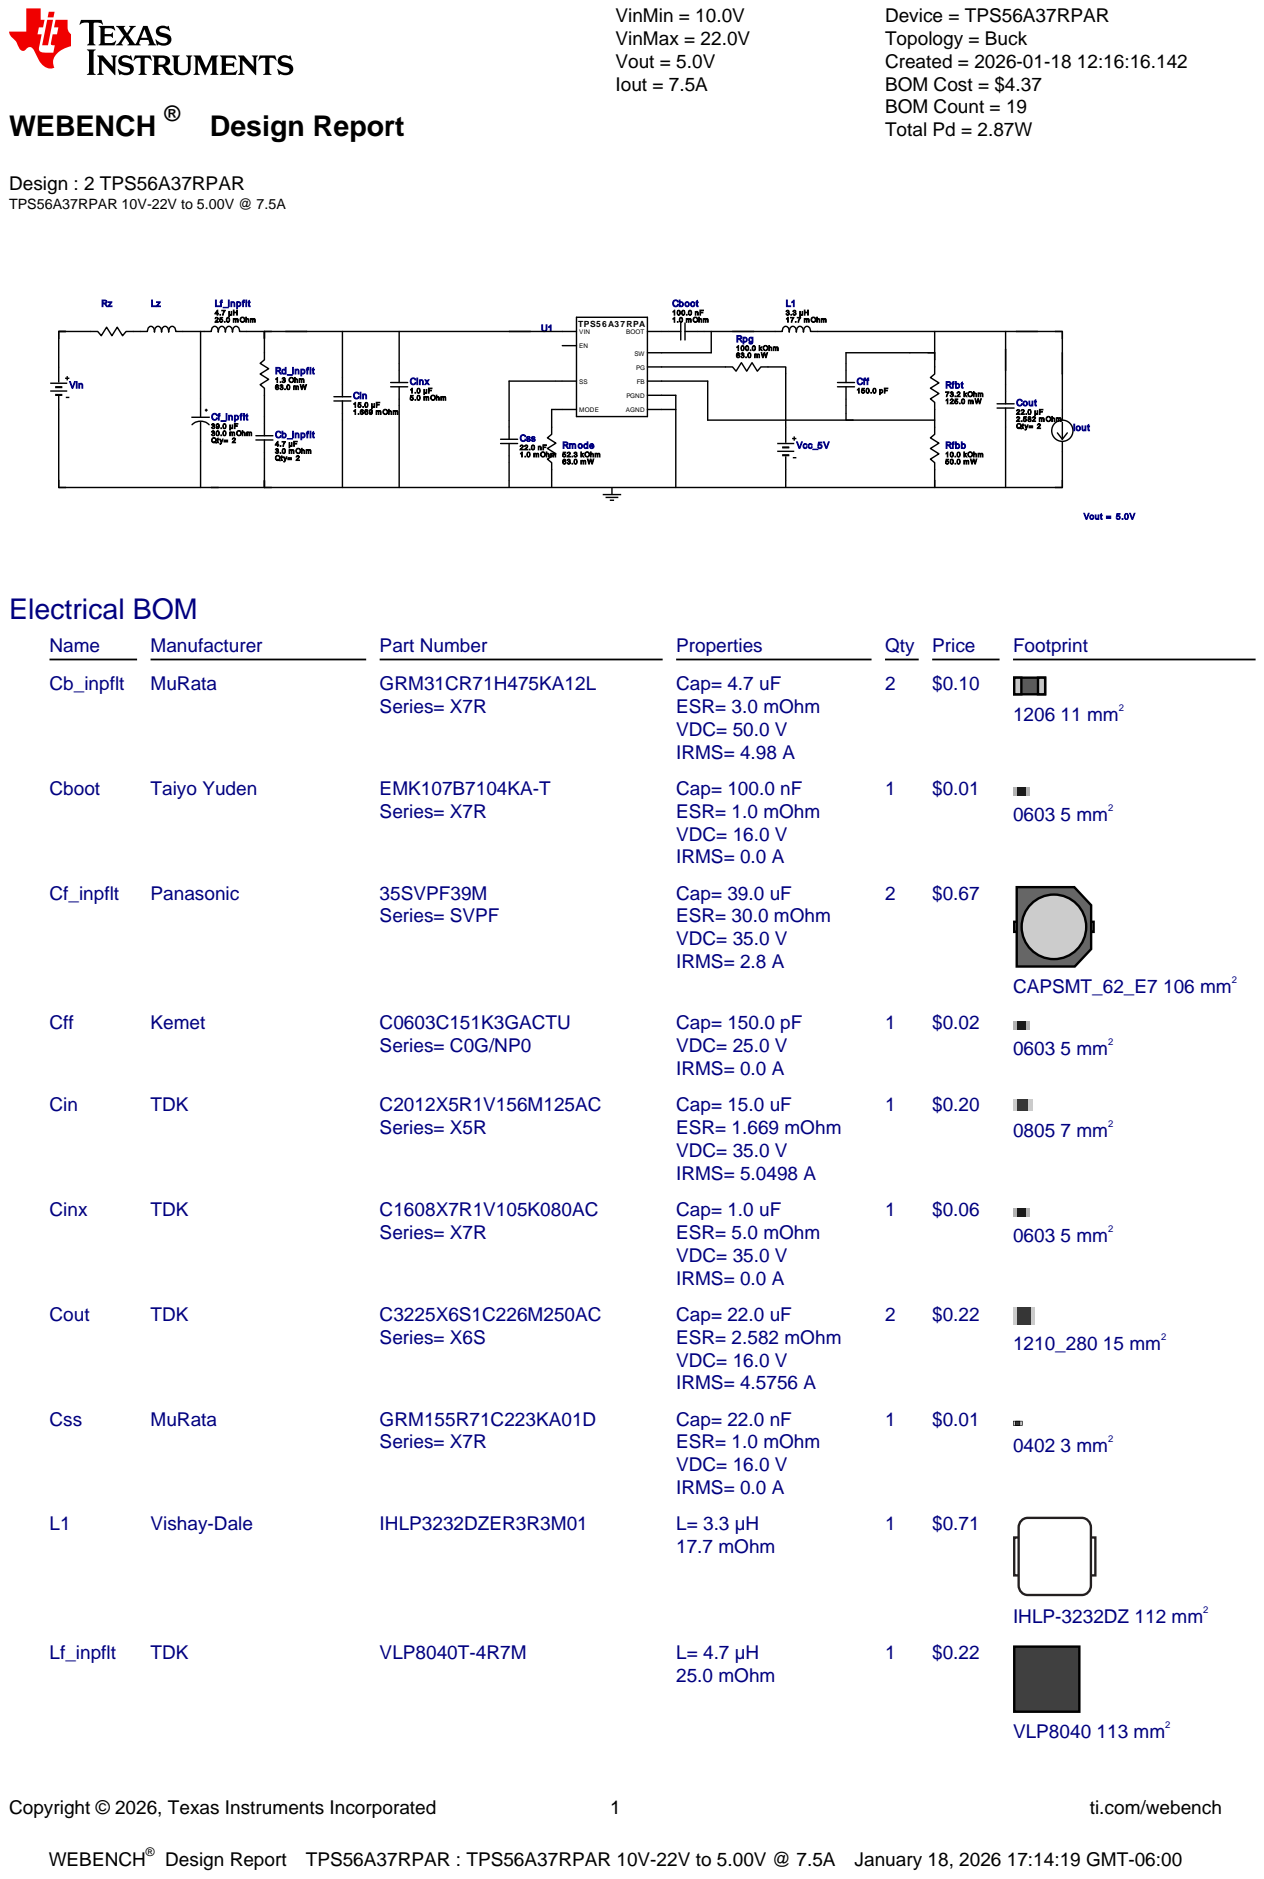
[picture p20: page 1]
Copyright © 2026, Texas Instruments Incorporated; ti.com/webench; WEBENCH®; Design : 2 TPS56A37RPAR TPS56A37RPAR 10V-22V to 5.00V @ 7.5A; VinMin = 10.0V VinMax = 22.0V Vout = 5.0V Iout = 7.5A; Device = TPS56A37RPAR Topology = Buck Created = 2026-01-18 12:16:16.142 BOM Cost = $4.37 BOM Count = 19 Total Pd = 2.87W; Cin 15.0 µF; 1.669 m Ohm; Cout 22.0 µF; 2.582 m Ohm Qty= 2; Rfbb 10.0 kOhm 50.0 m W; Rfbt 73.2 kOhm; L1 3.3 µH 17.7 m Ohm; Cboot 100.0 nF; 1.0 m Ohm; Vcc_5V; Vout = 5.0V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

Cff 150.0 pF Cinx
5.0 m Ohm

Design Report TPS56A37RPAR : TPS56A37RPAR 10V-22V to 5.00V @ 7.5A January 18, 2026 17:14:19 GMT-06:00

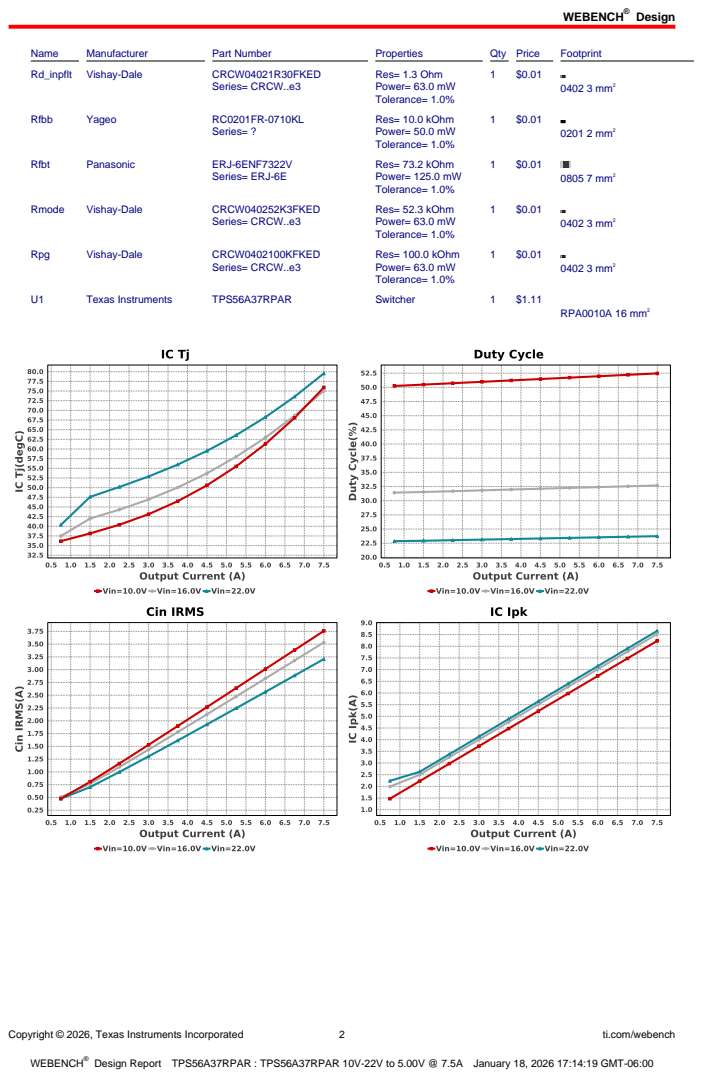
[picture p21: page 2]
Design; Copyright © 2026, Texas Instruments Incorporated; ti.com/webench; Name; Manufacturer; Part Number; Properties; Qty Price; Footprint; Rd_inpflt Vishay-Dale; CRCW04021R30FKED; Series= CRCW..e3; Res= 1.3 Ohm Power= 63.0 mW Tolerance= 1.0%; 0402 3 mm²; Rfbb; Yageo; Series= ?; Res= 10.0 kOhm Power= 50.0 mW Tolerance= 1.0%; 0201 2 mm²; Rfbt; Panasonic; ERJ-6ENF7322V; Series= ERJ-6E; Res= 73.2 kOhm Power= 125.0 mW Tolerance= 1.0%; 0805 7 mm²; Rmode; Vishay-Dale; CRCW040252K3FKED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

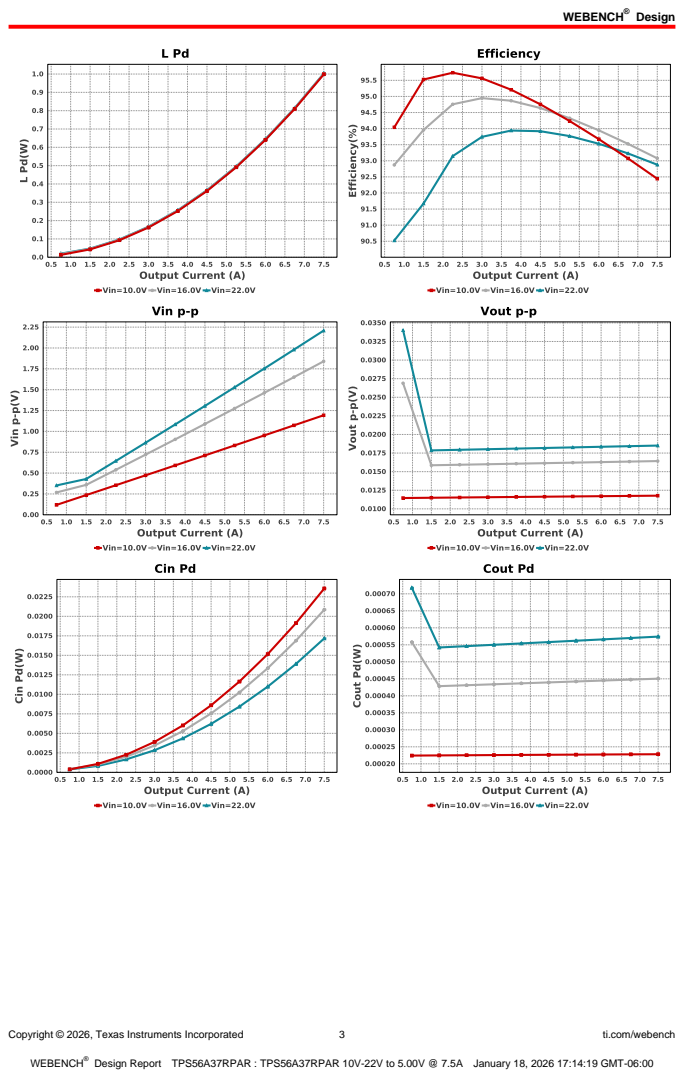
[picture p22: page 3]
Copyright © 2026, Texas Instruments Incorporated; ti.com/webench

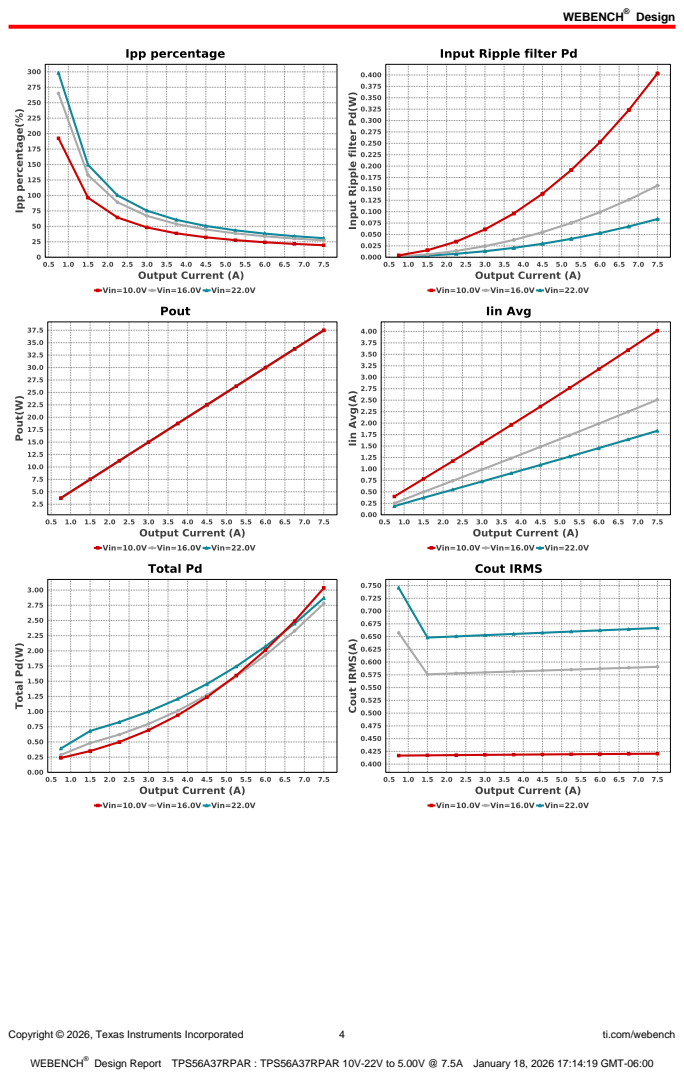
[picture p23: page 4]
Copyright © 2026, Texas Instruments Incorporated; ti.com/webench

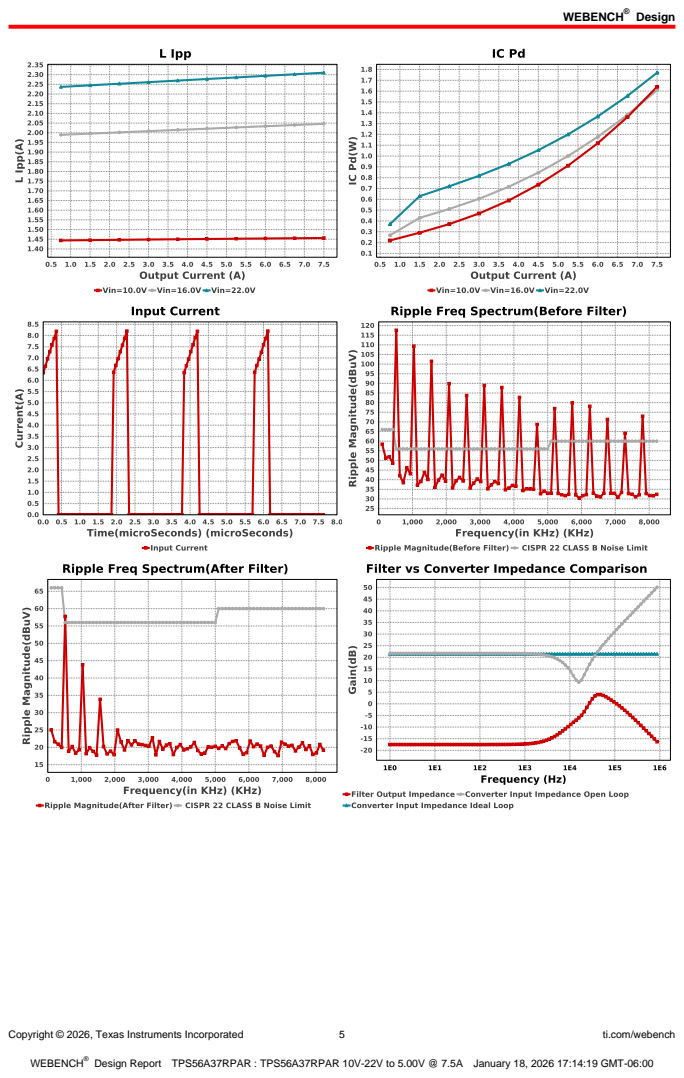
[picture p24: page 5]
Copyright © 2026, Texas Instruments Incorporated; ti.com/webench

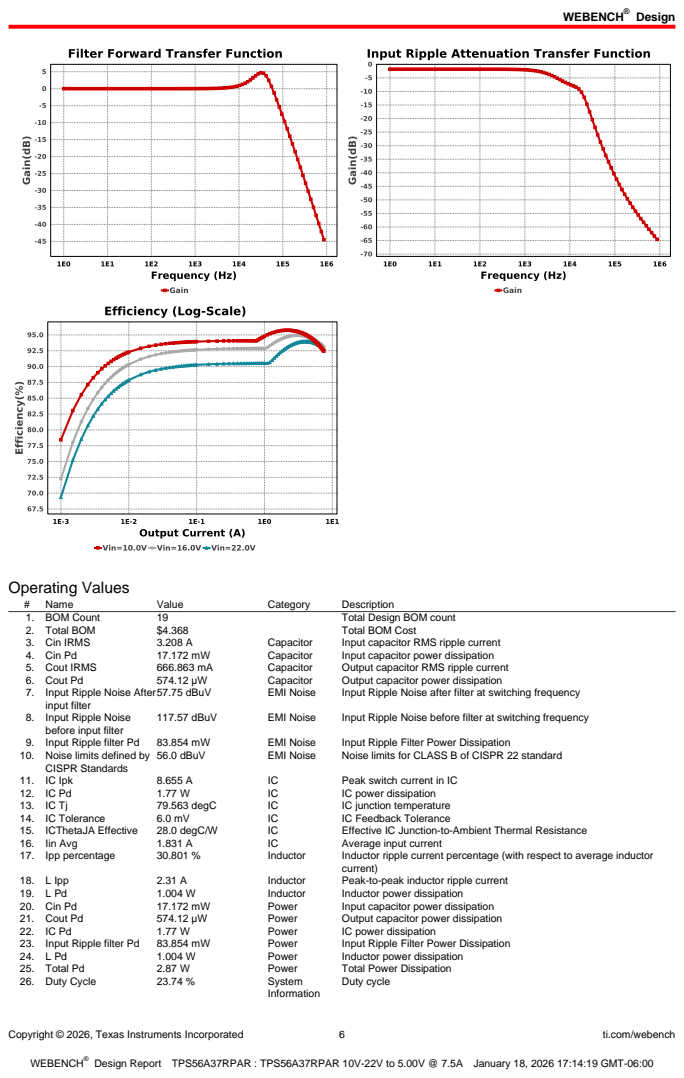
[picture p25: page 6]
Copyright © 2026, Texas Instruments Incorporated; ti.com/webench; Name; Value; Category; Description; 1. BOM Count; Total Design BOM count; 2. Total BOM; Total BOM Cost; 3. Cin IRMS; Capacitor; Input capacitor RMS ripple current; 4. Cin Pd; Input capacitor power dissipation; 5. Cout IRMS; Output capacitor RMS ripple current; 6. Cout Pd; Output capacitor power dissipation; 57.75 dBuV; EMI Noise; Input Ripple Noise after filter at switching frequency; 117.57 dBuV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

Operating Values
7. Input Ripple Noise After
input filter
8. Input Ripple Noise
before input filter
10. Noise limits defined by
CISPR Standards

Copyright © 2026, Texas Instruments Incorporated | 7 | ti.com/webench
# | Name | Value | Category | Description

27. Efficiency | 92.878 % | System
| | | Information | Steady state efficiency
28. FootPrint | 546.0 mm² | System
| | | Information | Total Foot Print Area of BOM components
29. Frequency | 520.497 kHz | System
| | | Information | Switching frequency
30. Iout | 7.5 A | System
| | | Information | Iout operating point
31. Mode | CCM | System
| | | Information | Conduction Mode
32. Pout | 37.5 W | System
| | | Information | Total output power
33. Vin | 22.0 V | System
| | | Information | Vin operating point
34. Vin p-p | 2.208 V | System
| | | Information | Peak-to-peak input voltage
35. Vout | 5.0 V | System
| | | Information | Operational Output Voltage
36. Vout Actual | 4.992 V | System
| | | Information | Vout Actual calculated based on selected voltage divider resistors
37. Vout Tolerance | 2.795 % | System
| | | Information | Vout Tolerance based on IC Tolerance (no load) and voltage divider resistors if applicable
38. Vout p-p | 18.507 mV | System
| | | Information | Peak-to-peak output ripple voltage

## Design Inputs

Name | Value | Description
Iout | 7.5 | Maximum Output Current
VinMax | 22.0 | Maximum input voltage
VinMin | 10.0 | Minimum input voltage
Vout | 5.0 | Output Voltage
| base_pn | | TPS56A37 | Base Product Number
source | DC | Input Source Type
Ta | 30.0 | Ambient temperature


Copyright © 2026, Texas Instruments Incorporated | 8 | ti.com/webench

## Assembly

## Component Testing

Some published data on components in datasheets such as Capacitor ESR and Inductor DC resistance is based on conservative values that will guarantee that the components always exceed the specification. For design purposes it is usually better to work with typical values. Since this data is not always available it is a good practice to measure the Capacitance and ESR values of Cin and Cout, and the inductance and DC resistance of L1 before assembly of the board. Any large discrepancies in values should be electrically simulated in WEBENCH to check for instabilities and thermally simulated in WebTHERM to make sure critical temperatures are not exceeded.
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

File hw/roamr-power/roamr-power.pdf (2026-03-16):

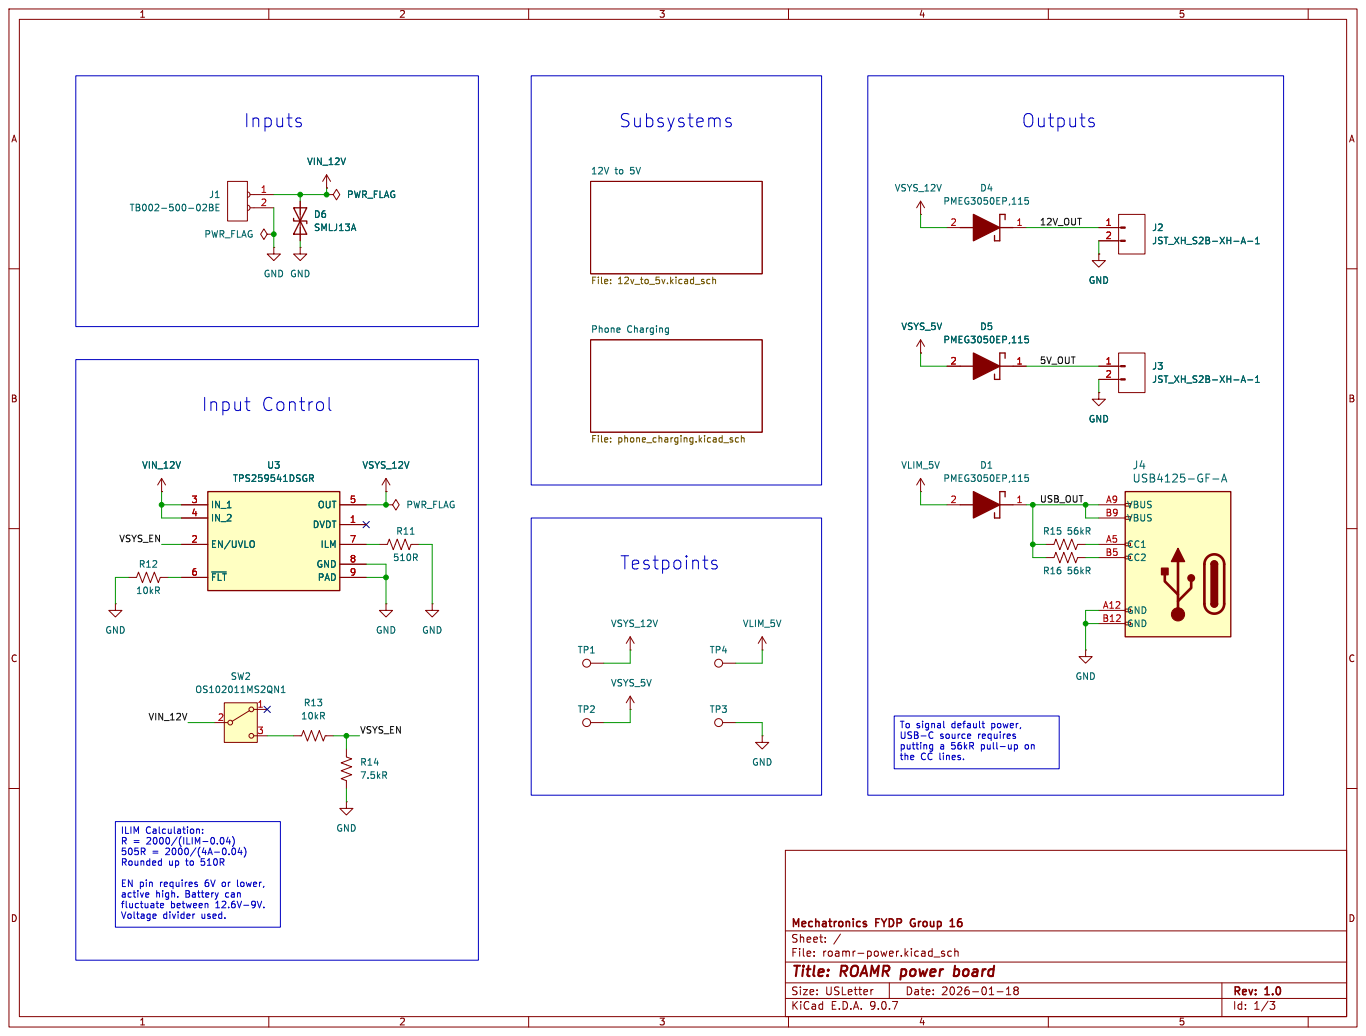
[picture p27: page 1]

ILIM Calculation: R = 2000/(ILIM-0.04) 505R = 2000/(4A-0.04) Rounded up to 510R

EN pin requires 6V or lower, active high. Battery can

Id: 1/3 Title: ROAMR power board

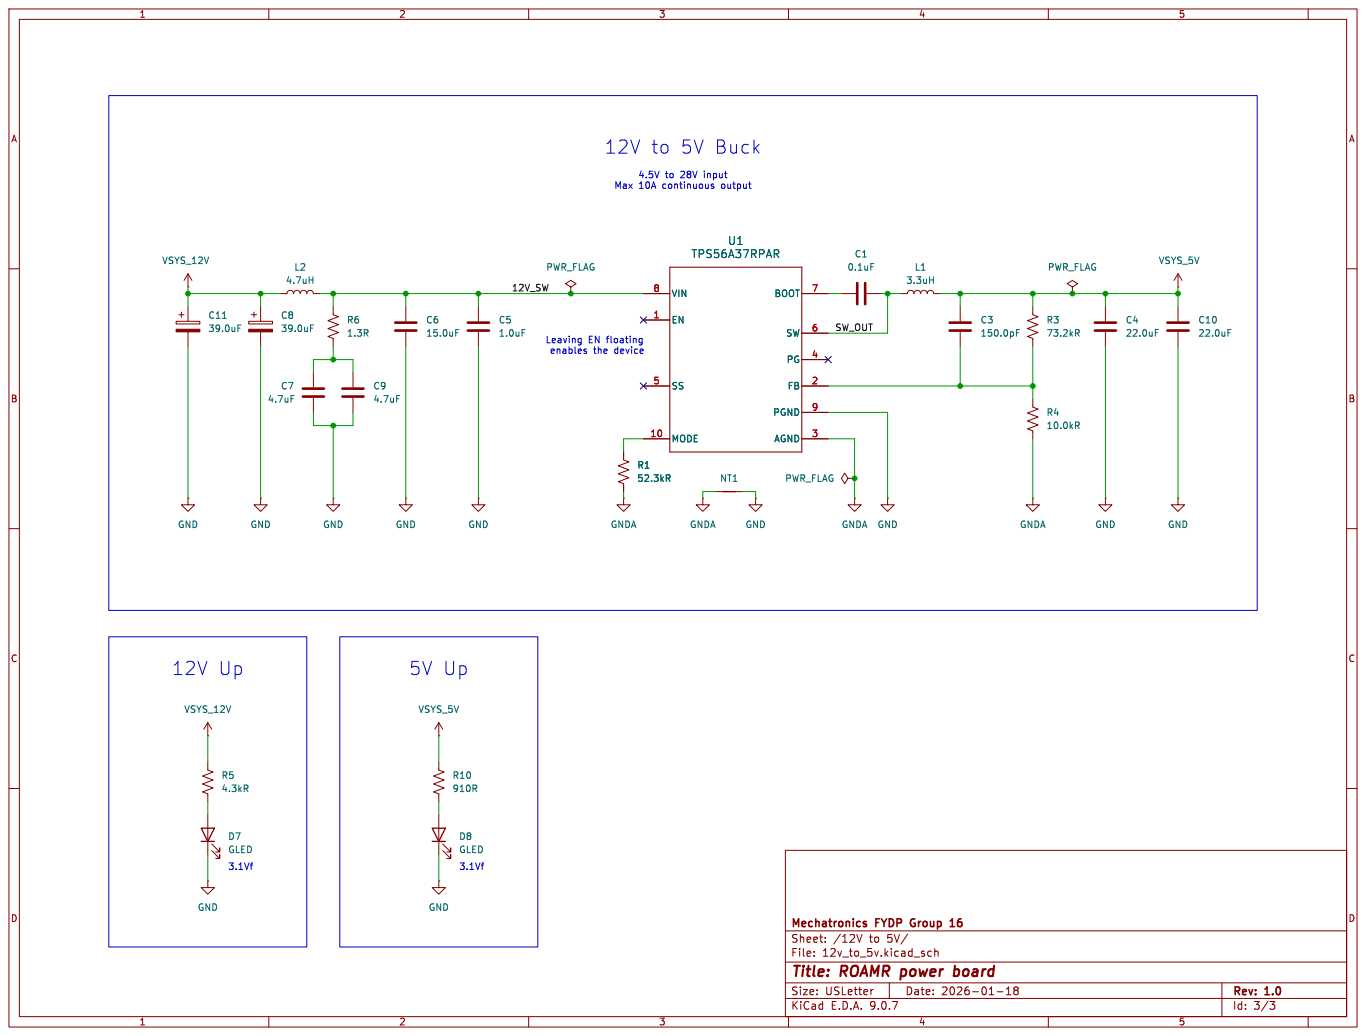
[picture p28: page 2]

enables the device 5V Up

Id: 3/3 Title: ROAMR power board

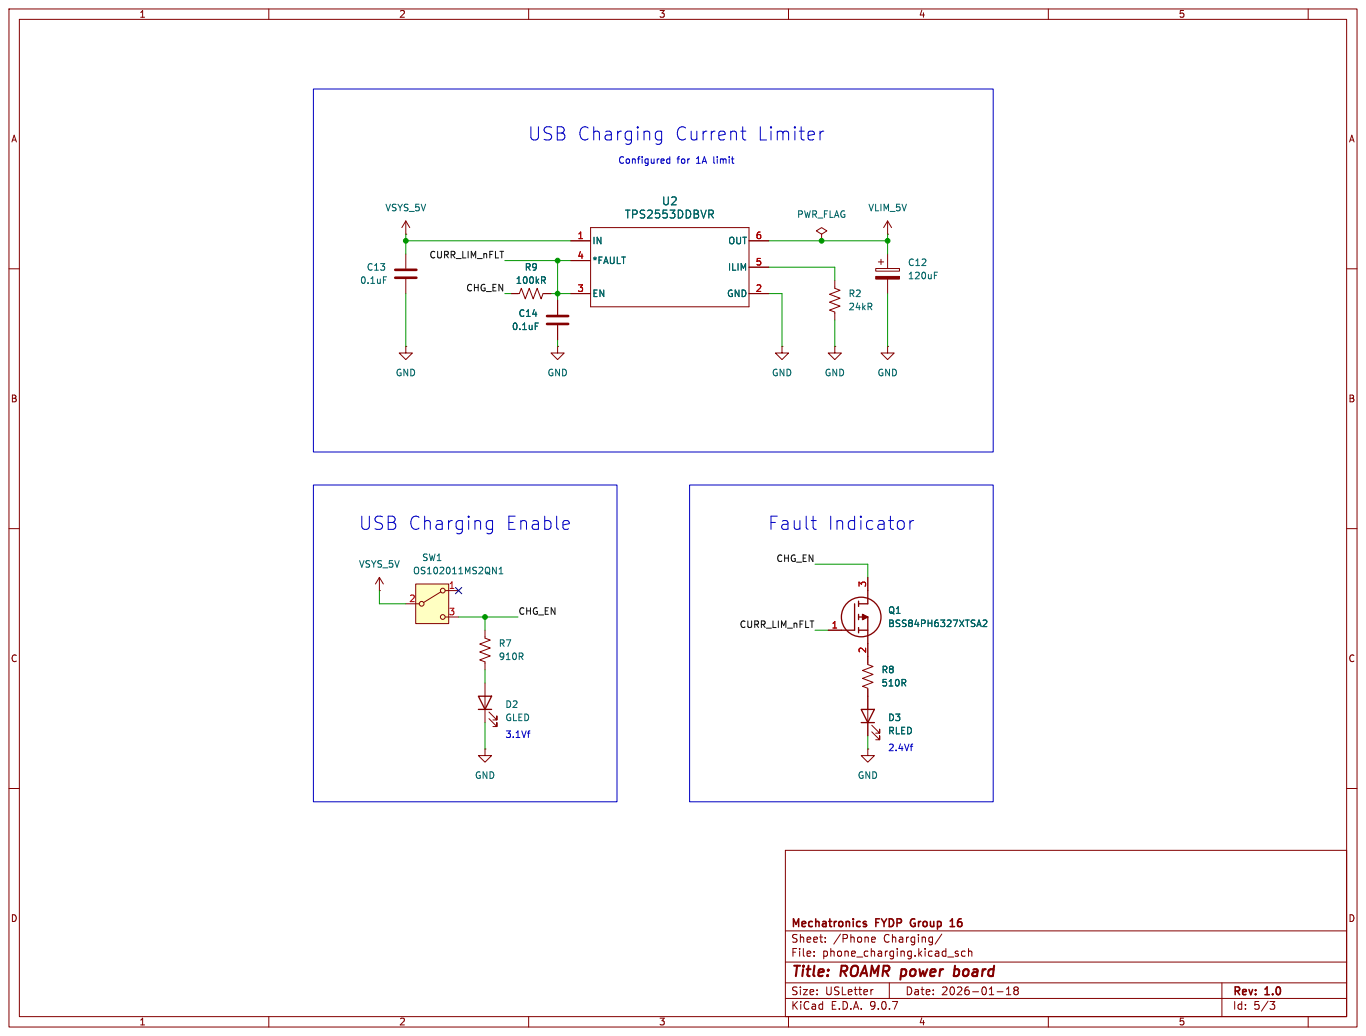
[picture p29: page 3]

Id: 5/3 Title: ROAMR power board

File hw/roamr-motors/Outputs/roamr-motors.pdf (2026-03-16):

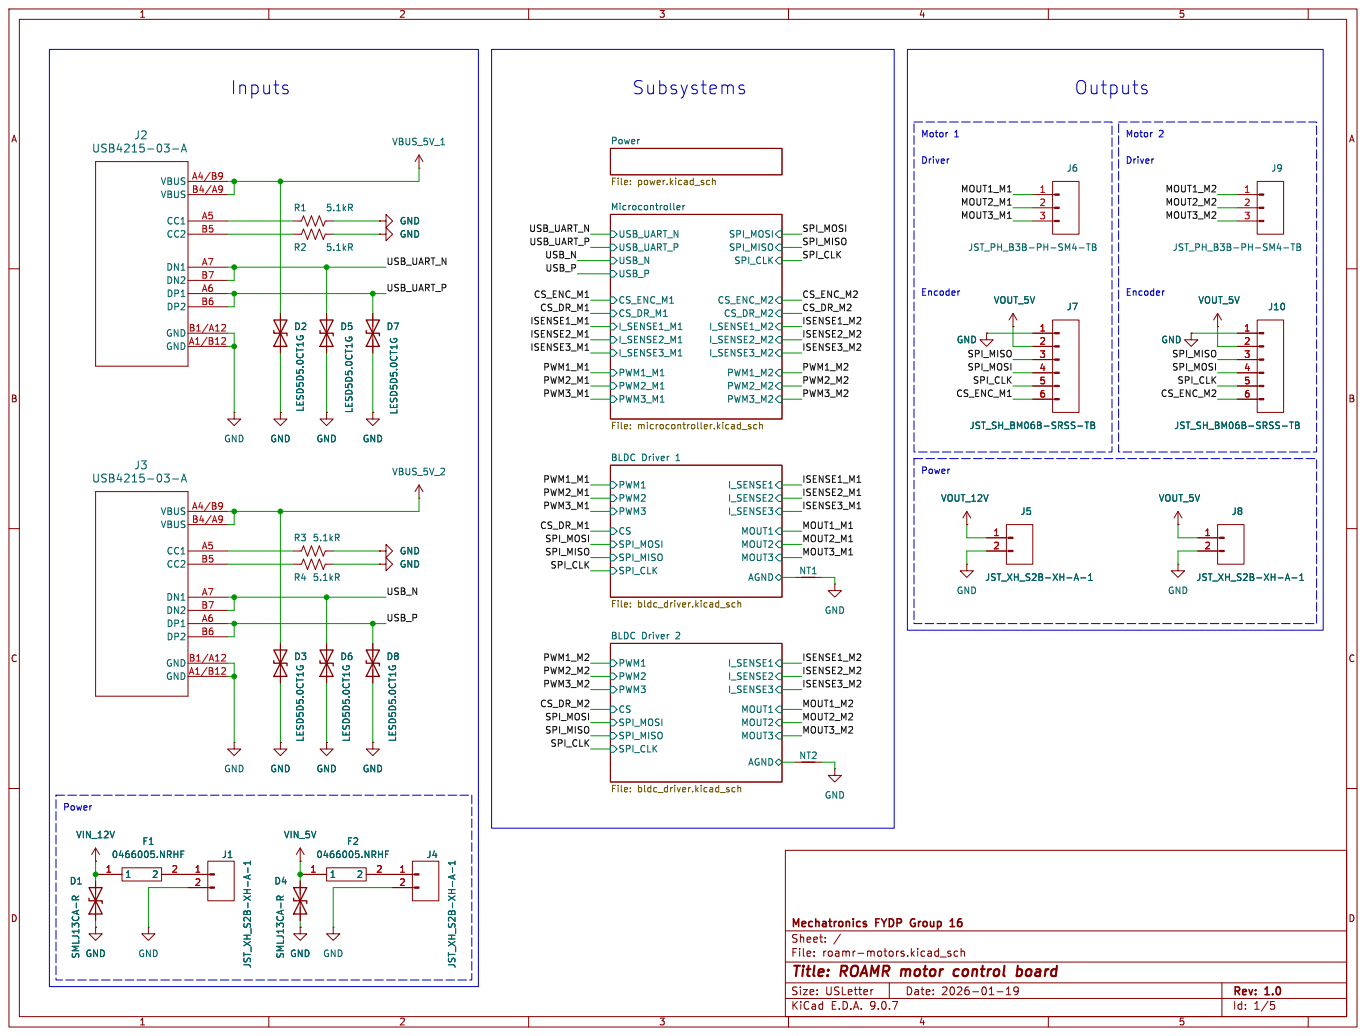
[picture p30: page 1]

Power File: power.kicad_sch CS

Id: 1/5 Title: ROAMR motor control board

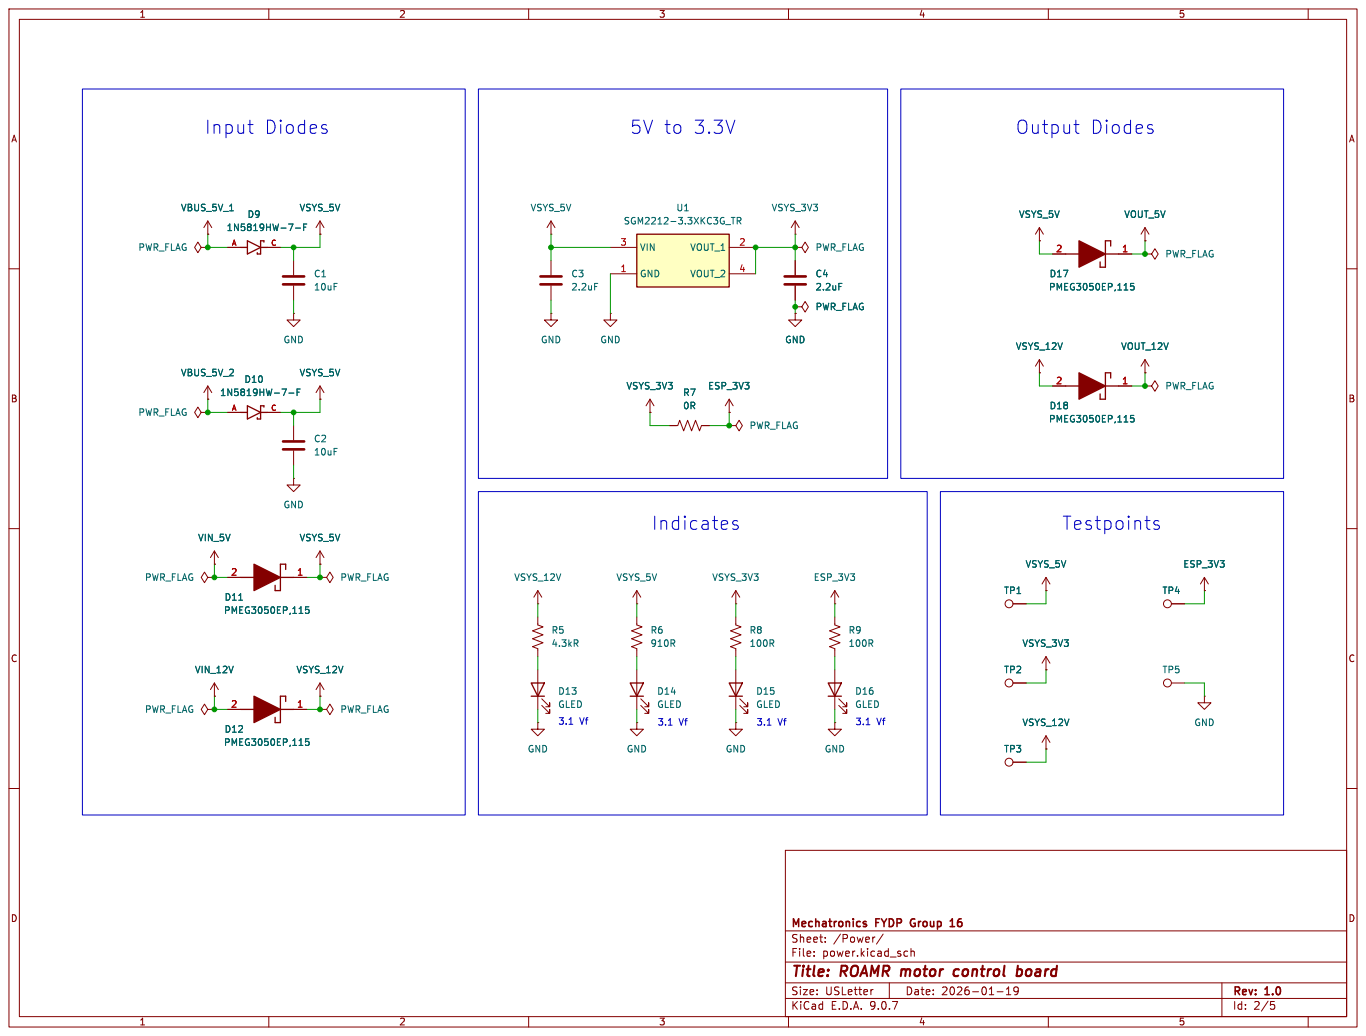
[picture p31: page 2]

Id: 2/5 Title: ROAMR motor control board


2.4 Vf USB to UART

FSPICLK: CLK RX / TX correctly

3 TXD 26 RXD 25 ~{RTS} 24 ~{CTS} 23 ~{DSR} 27 ~{DTR} 28 ~{DCD} 1 ~{RI}/CLK 2 SUSPEND 12 ~{SUSPEND} 11 ~{TXT}/GPIO.0 19 ~{RXT}/GPIO.1 18 RS485/GPIO.2 17 ~{WAKEUP}/GPIO.3 16 GPIO.4 22 GPIO.5 21 GPIO.6 20 CHREN 13 CHR0 15 CHR1 14 U2 CP2102N-A02-GQFN28 R10

3 TXD 26 RXD 25 ~{RTS} 24 ~{CTS} 23 ~{DSR} 27 ~{DTR} 28 ~{DCD} 1 ~{RI}/CLK 2 SUSPEND 12 ~{SUSPEND} 11 ~{TXT}/GPIO.0 19 ~{RXT}/GPIO.1 18 RS485/GPIO.2 17 ~{WAKEUP}/GPIO.3 16 GPIO.4 22 GPIO.5 21 GPIO.6 20 CHREN 13 CHR0 15 CHR1 14 R10

(PSRAM). Instead, we
use SPI2 also known as Fast SPI "FSPI". FSPID: MOSI FSPIQ: MISO

Id: 3/5 Title: ROAMR motor control board


INL always high,
INH inputs PWM to
drive H/L/HighZ.
Requires "10b" to
be sent over SPI
to configure.

Id: 4/5 Title: ROAMR motor control board

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

Id: 5/5 Title: ROAMR motor control board

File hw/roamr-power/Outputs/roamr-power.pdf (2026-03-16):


the CC lines. Subsystems

File: 12v_to_5v.kicad_sch Phone Charging File: phone_charging.kicad_sch

ILIM Calculation: R = 2000/(ILIM-0.04) 505R = 2000/(4A-0.04) Rounded up to 510R

EN pin requires 6V or lower, active high. Battery can

Id: 1/3 Title: ROAMR power board


Id: 3/3 Title: ROAMR power board


Id: 5/3 Title: ROAMR power board

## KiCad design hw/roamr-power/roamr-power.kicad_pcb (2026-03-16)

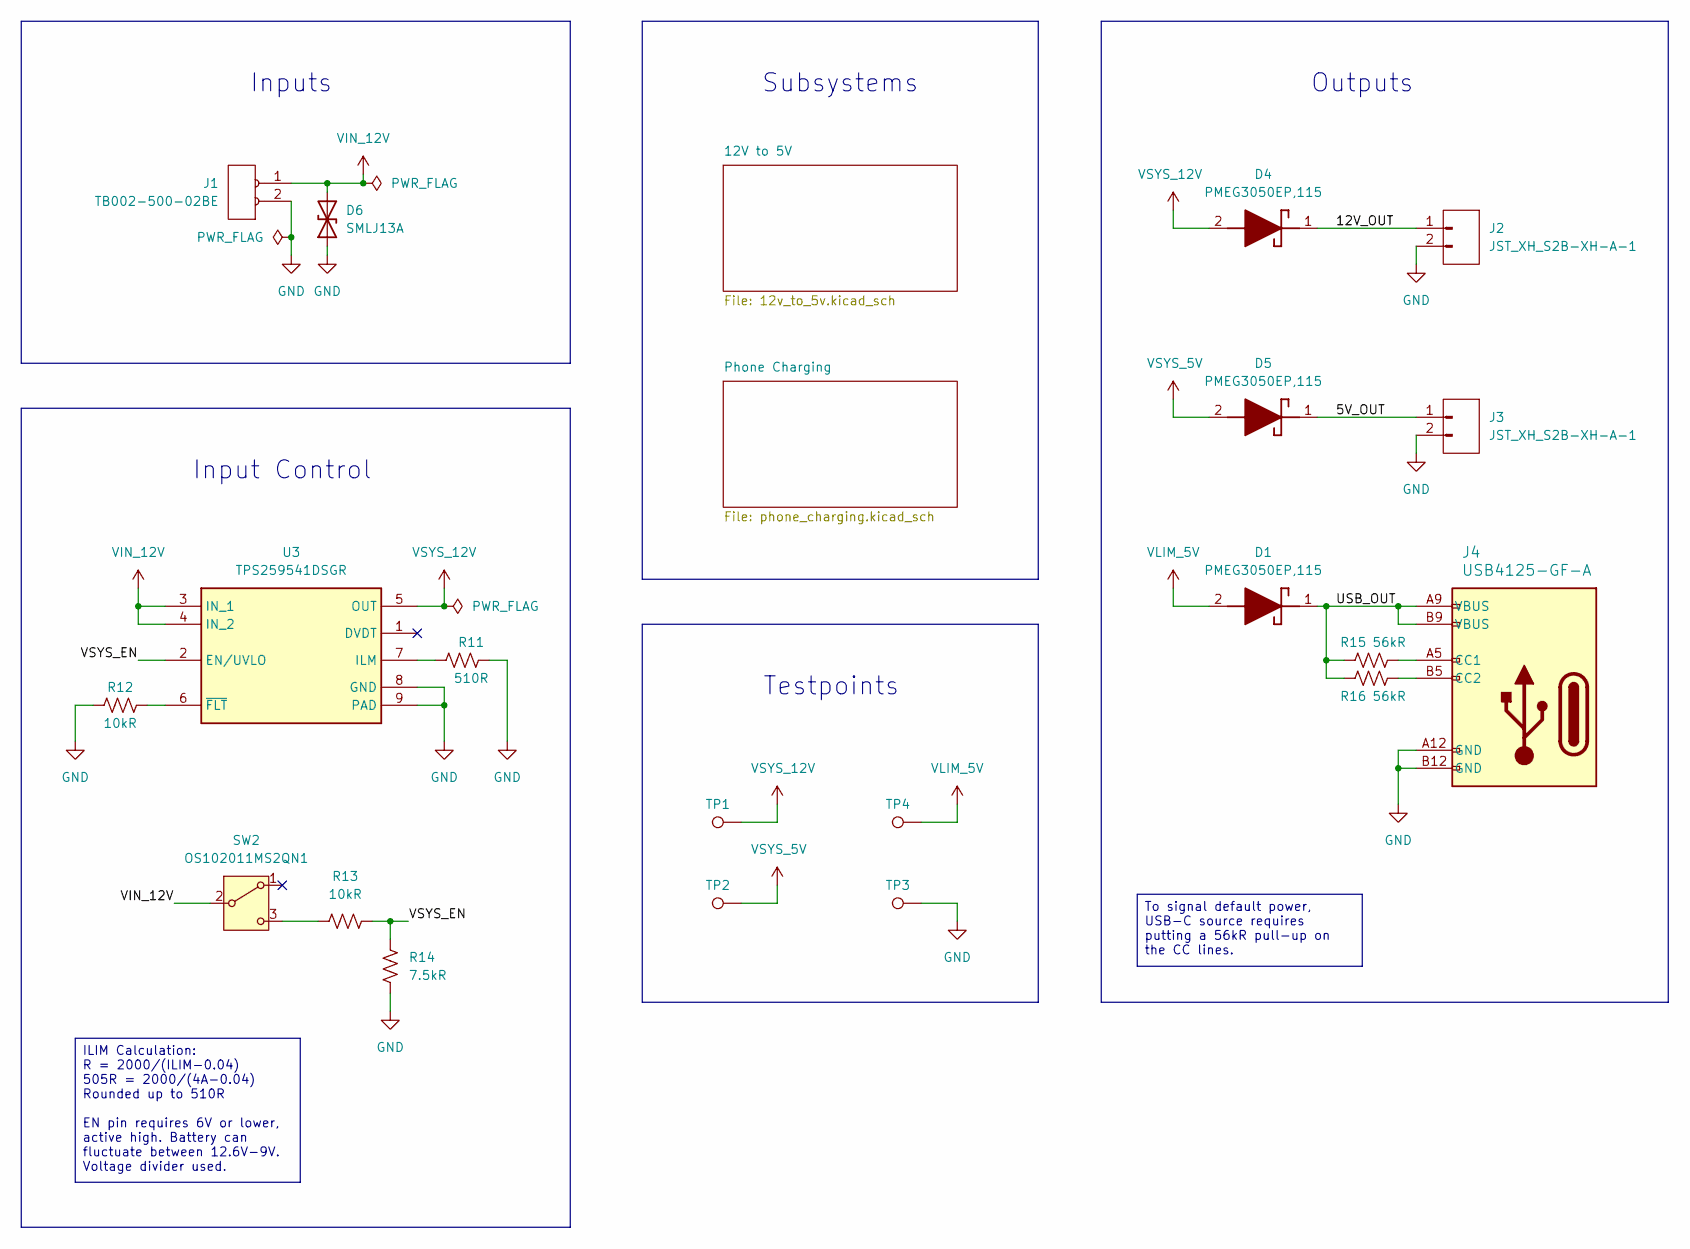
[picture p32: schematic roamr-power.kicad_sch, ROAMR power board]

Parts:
D1, D4, D5: PMEG3050EP,115; PMEG3050EP115; Mouser Part Number 771-PMEG3050EP115
D6: SMLJ13A; DIOM7959X262N; Manufacturer_Part_Number SMLJ13A
J1: TB002-500-02BE; TB00250002BE; Manufacturer_Part_Number TB002-500-02BE
J2, J3: JST_XH_S2B-XH-A-1; JST_XH_S2B-XH-A-1_1x02_P2.50mm_Horizontal; Manufacturer_Part_Number JST_XH_S2B-XH-A-1
J4: USB4125-GF-A; USB4125GFA; Manufacturer_Part_Number USB4125-GF-A
R11: 510R; R_0603_1608Metric
R12, R13: 10kR; R_0603_1608Metric
R14: 7.5kR; R_0603_1608Metric
R15, R16: 56kR; R_0603_1608Metric
SW2: OS102011MS2QN1; OS102011MA1QN1; Manufacturer_Part_Number OS102011MS2QN1
TP1, TP2, TP4: TestPoint; TestPoint_Pad_D1.5mm
TP3: TestPoint; TestPoint_Keystone_5005-5009_Compact; Manufacturer_Part_Number 5005-5009
U3: TPS259541DSGR; SON50P200X200X80-9N; Mouser Part Number 595-TPS259541DSGR

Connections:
/5V_OUT: D5.1 (K), J3.1
/12V_OUT: D4.1 (K), J2.1
/USB_OUT: D1.1 (K), J4.A9 (VBUS), J4.B4 (VBUS), J4.B9 (VBUS), R15.1, R16.1
/VSYS_EN: R13.2, R14.1, U3.2 (EN/UVLO)
GND: D6.1 (A1), J1.2, J2.2, J3.2, J4.A12 (GND), J4.B12 (GND), R11.2, R12.1, R14.2, TP3.1, U3.8 (GND), U3.9 (PAD); also elsewhere on the board
unnamed: J4.A5 (CC1), R15.2
unnamed: J4.B5 (CC2), R16.2
unnamed: R13.1, SW2.3 (C)
unnamed: R11.1, U3.7 (ILM)
unnamed: R12.2, U3.6 (~FLT)
VIN_12V: D6.2 (A2), J1.1, SW2.2 (B), U3.3 (IN_1), U3.4 (IN_2)
VLIM_5V: D1.2 (A), TP4.1; also elsewhere on the board
VSYS_5V: D5.2 (A), TP2.1; also elsewhere on the board
VSYS_12V: D4.2 (A), TP1.1, U3.5 (OUT); also elsewhere on the board

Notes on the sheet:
Input Control
Inputs
Subsystems
Outputs
Testpoints
ILIM Calculation: R = 2000/(ILIM-0.04) 505R = 2000/(4A-0.04) Rounded up to 510R EN pin requires 6V or lower, active high. Battery can fluctuate between 12.6V-9V. Voltage divider used.
To signal default power, USB-C source requires putting a 56kR pull-up on the CC lines.

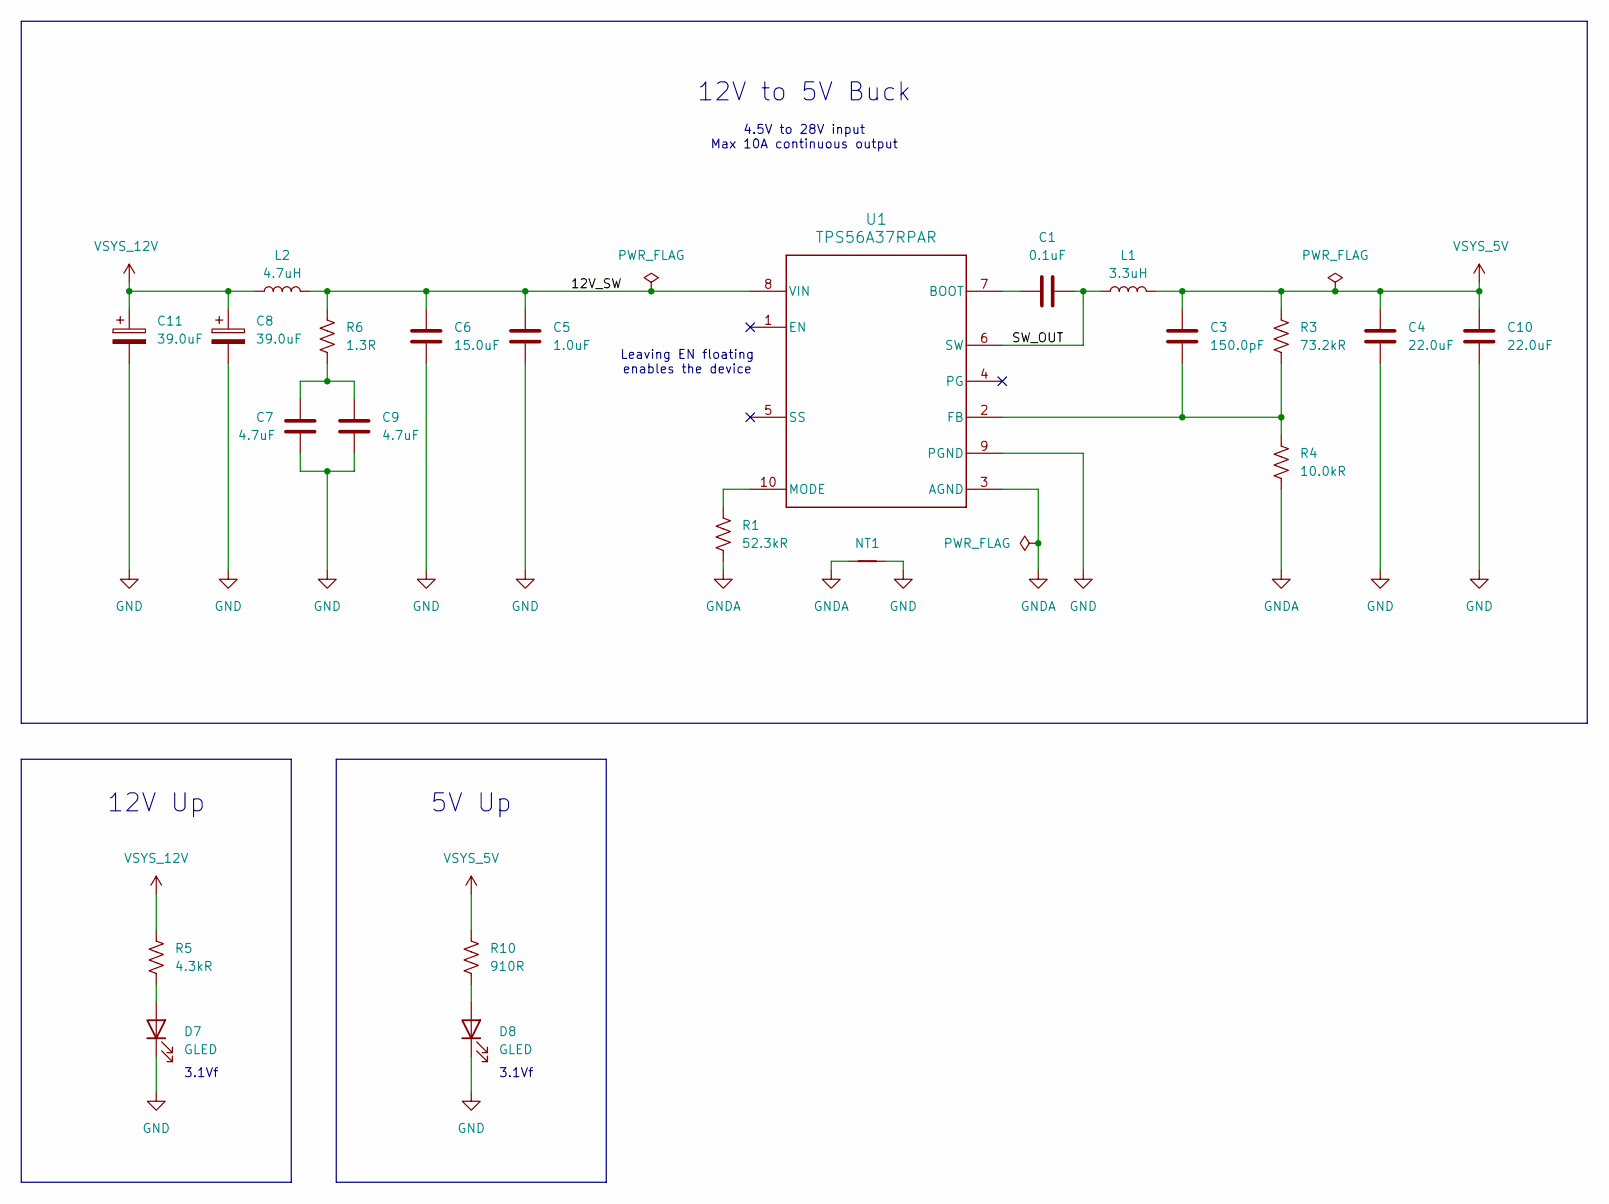
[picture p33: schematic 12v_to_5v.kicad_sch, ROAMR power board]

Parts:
C1: 0.1uF; C_0603_1608Metric
C3: 150.0pF; C_0603_1608Metric
C4, C10: 22.0uF; C_0603_1608Metric
C5: 1.0uF; C_0603_1608Metric
C6: 15.0uF; C_0805_2012Metric
C7, C9: 4.7uF; C_0603_1608Metric
C8, C11: 39.0uF; 16SVF270M
D7, D8: GLED; LEDC1608X70N; Manufacturer_Part_Number KT-0603G
L1: 3.3uH; IND_PCC-M0645M_PAN-L; Manufacturer_Part_Number ETQ-L4M3R3YFN
L2: 4.7uH; IND_VLS6045EX-4R7M_TDK; Manufacturer_Part_Number VLS6045EX
NT1: NetTie_2; NetTie-2_SMD_Pad0.5mm
R1: 52.3kR; R_0603_1608Metric
R3: 73.2kR; R_0603_1608Metric
R4: 10.0kR; R_0603_1608Metric
R5: 4.3kR; R_0603_1608Metric
R6: 1.3R; R_0603_1608Metric
R10: 910R; R_0603_1608Metric
U1: TPS56A37RPAR; RPA0010A-MFG; Manufacturer_Part_Number TPS56A37RPAR

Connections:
/12V to 5V/12V_SW: C5.1, C6.1, L2.2, R6.1, U1.8 (VIN)
/12V to 5V/SW_OUT: C1.2, L1.1, U1.6 (SW)
GND: C4.2, C5.2, C6.2, C7.2, C8.2, C9.2, C10.2, C11.2, D7.1 (K), D8.1 (K), NT1.2, U1.9 (PGND); also elsewhere on the board
GNDA: NT1.1, R1.1, R4.1, U1.3 (AGND)
unnamed: C7.1, C9.1, R6.2
unnamed: D7.2 (A), R5.2
unnamed: D8.2 (A), R10.2
unnamed: C1.1, U1.7 (BOOT)
unnamed: C3.2, R3.1, R4.2, U1.2 (FB)
unnamed: R1.2, U1.10 (MODE)
VSYS_5V: C3.1, C4.1, C10.1, L1.2, R3.2, R10.1; also elsewhere on the board
VSYS_12V: C8.1, C11.1, L2.1, R5.1; also elsewhere on the board

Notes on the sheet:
5V Up
3.1Vf
12V to 5V Buck
12V Up
3.1Vf
Leaving EN floating enables the device
4.5V to 28V input Max 10A continuous output

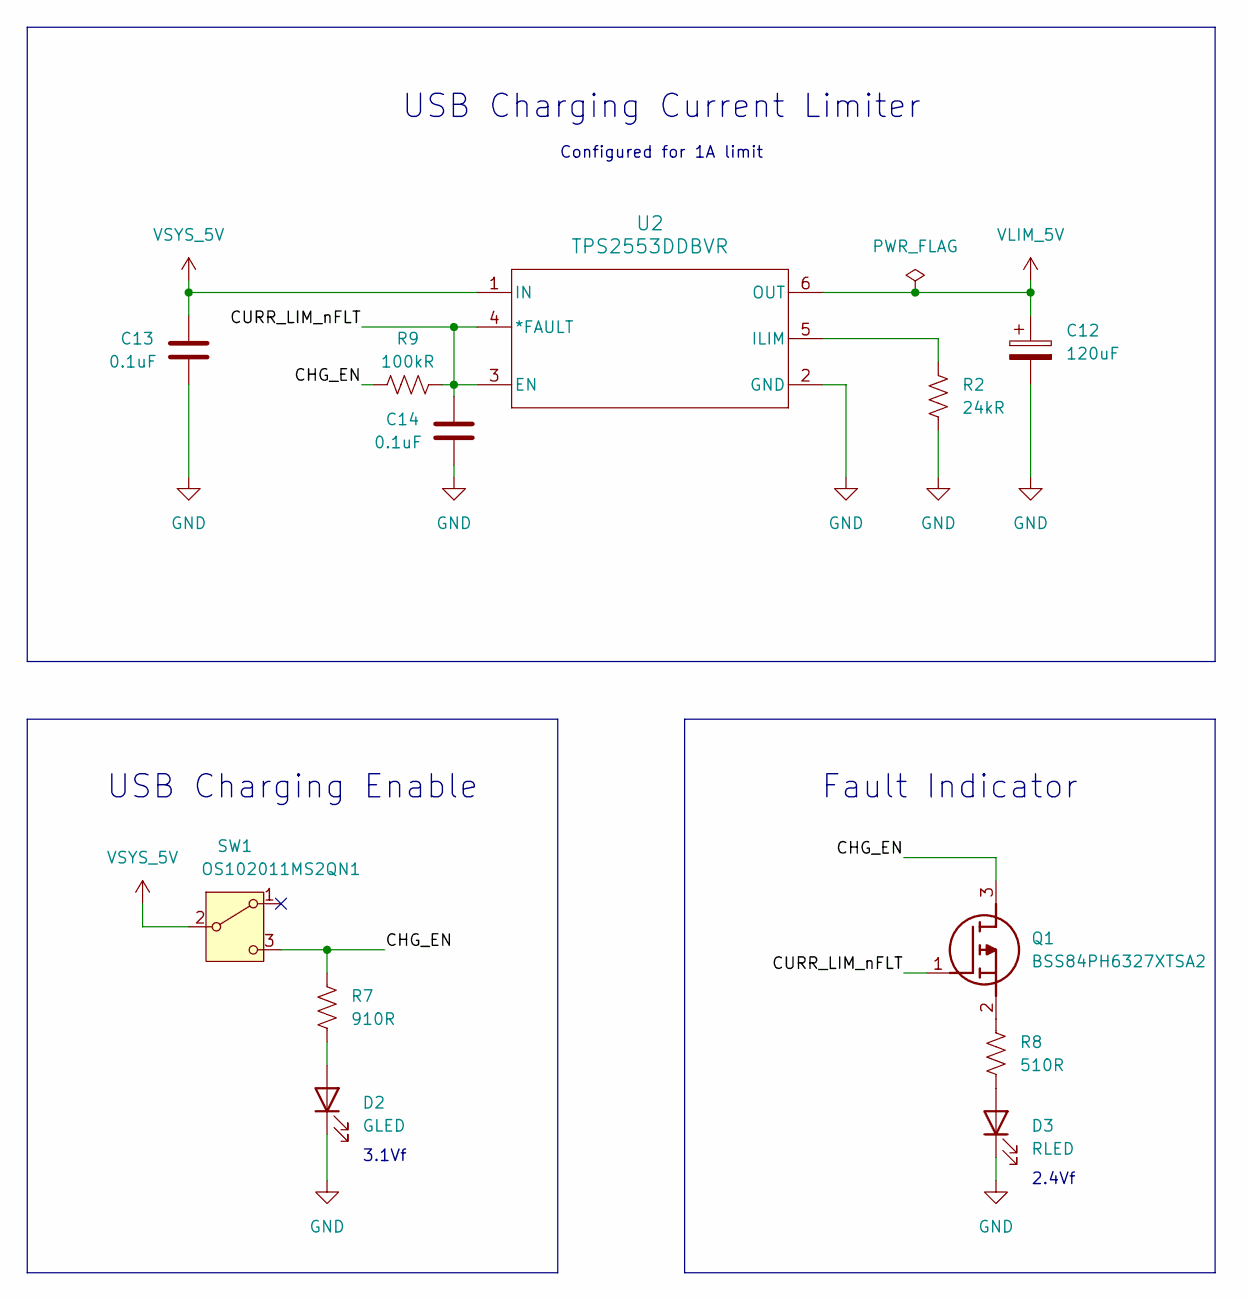
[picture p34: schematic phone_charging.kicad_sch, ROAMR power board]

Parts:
C12: 120uF; CAPAE660X610N
C13, C14: 0.1uF; C_0603_1608Metric
D2: GLED; LEDC1608X70N; Manufacturer_Part_Number KT-0603G
D3: RLED; LEDC1608X70N; Manufacturer_Part_Number KT-0603R
Q1: BSS84PH6327XTSA2; SOT95P240X110-3N; Mouser Part Number 726-BSS84PH6327XTSA2
R2: 24kR; R_0603_1608Metric
R7: 910R; R_0603_1608Metric
R8: 510R; R_0603_1608Metric
R9: 100kR; R_0603_1608Metric
SW1: OS102011MS2QN1; OS102011MA1QN1; Manufacturer_Part_Number OS102011MS2QN1
U2: TPS2553DDBVR; SOT95P280X145-6N; Manufacturer_Part_Number TPS2553DDBVR

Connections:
/Phone Charging/CHG_EN: Q1.3 (D), R7.1, R9.1, SW1.3 (C)
/Phone Charging/CURR_LIM_nFLT: C14.1, Q1.1 (G), R9.2, U2.3 (EN), U2.4 (*FAULT)
GND: C12.2, C13.2, C14.2, D2.1 (K), D3.1 (K), R2.2, U2.2 (GND); also elsewhere on the board
unnamed: D2.2 (A), R7.2
unnamed: D3.2 (A), R8.2
unnamed: Q1.2 (S), R8.1
unnamed: R2.1, U2.5 (ILIM)
VLIM_5V: C12.1, U2.6 (OUT); also elsewhere on the board
VSYS_5V: C13.1, SW1.2 (B), U2.1 (IN); also elsewhere on the board

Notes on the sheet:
USB Charging Enable
3.1Vf
USB Charging Current Limiter
2.4Vf
Fault Indicator
Configured for 1A limit

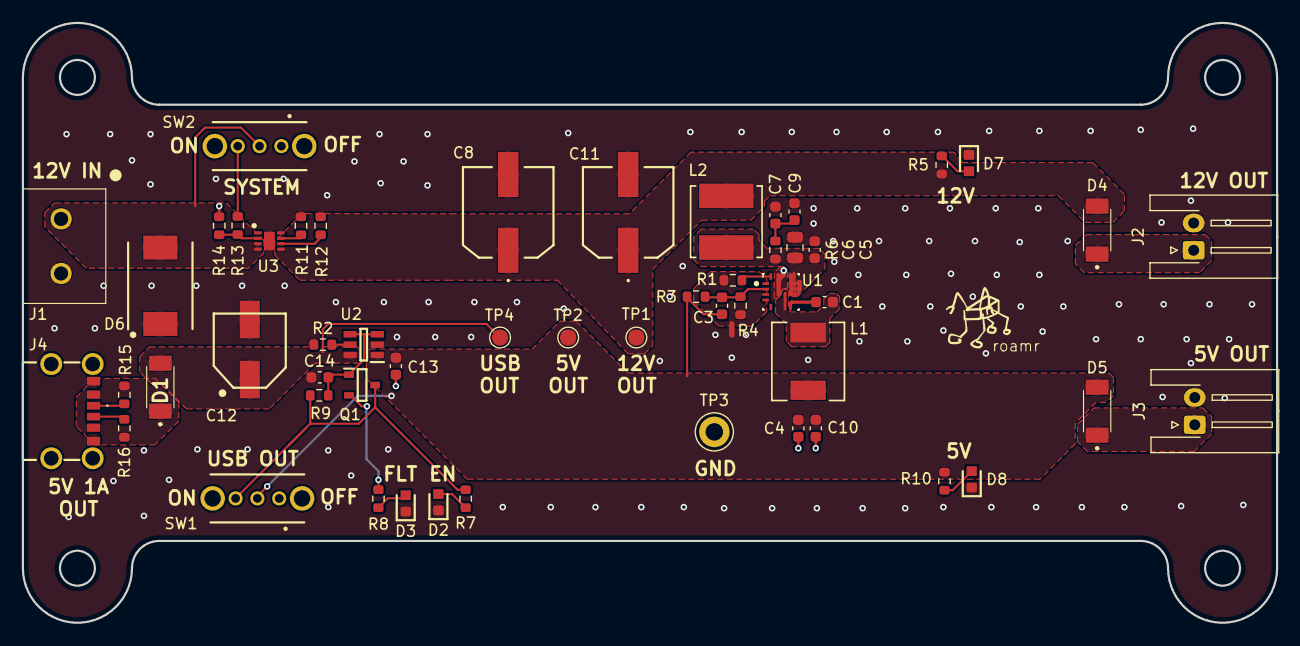
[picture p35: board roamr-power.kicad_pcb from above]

Board: 2 copper layers, 115.0 x 55.0 mm, 54 parts (0 on the bottom side), 29 nets.

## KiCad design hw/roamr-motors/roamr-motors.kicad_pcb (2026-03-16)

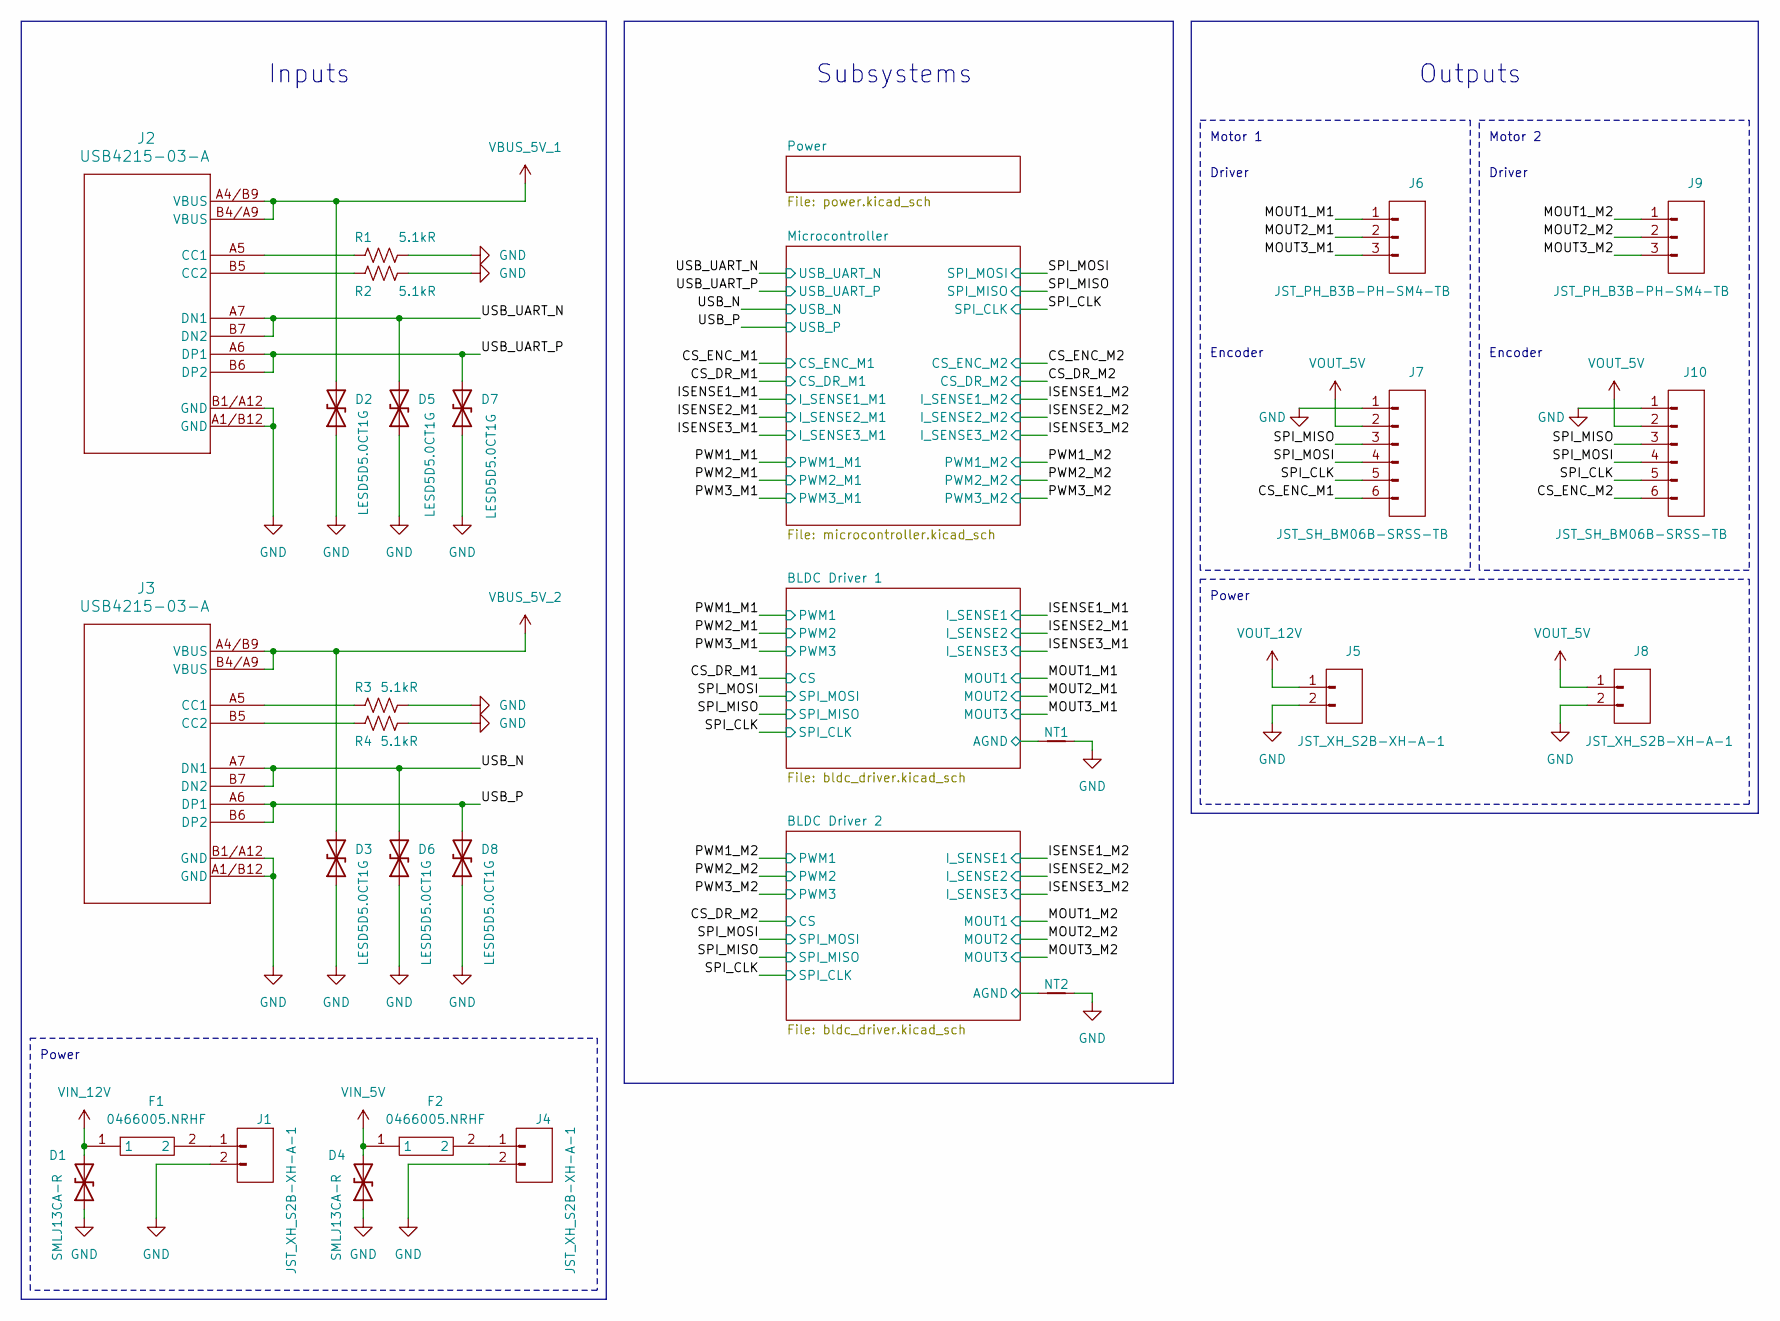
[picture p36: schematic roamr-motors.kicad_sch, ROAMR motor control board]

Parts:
D1, D4: SMLJ13CA-R; DIOM7959X262N; Manufacturer_Part_Number SMLJ13CA-R
D2, D3, D5, D6, D7, D8: LESD5D5.0CT1G; LESD5D50CT1G; Manufacturer_Part_Number LESD5D5.0CT1G
F1, F2: 0466005.NRHF; F1206; Manufacturer_Part_Number 0466005.NRHF; LCSC Part C57525
J1, J4, J5, J8: JST_XH_S2B-XH-A-1; JST_XH_S2B-XH-A-1_1x02_P2.50mm_Horizontal; Manufacturer_Part_Number JST_XH_S2B-XH-A-1
J2, J3: USB4215-03-A; CONN_8p94X6p5X3p16_12L_GCC; Manufacturer_Part_Number USB4215-03-A
J6, J9: JST_PH_B3B-PH-SM4-TB; JST_PH_B3B-PH-SM4-TB_1x03-1MP_P2.00mm_Vertical; Manufacturer_Part_Number JST_PH_B3B-PH-SM4-TB
J7, J10: JST_SH_BM06B-SRSS-TB; JST_SH_BM06B-SRSS-TB_1x06-1MP_P1.00mm_Vertical; Manufacturer_Part_Number JST_SH_BM06B-SRSS-TB
NT1, NT2: NetTie_2; NetTie-2_SMD_Pad0.5mm
R1, R2, R3, R4: 5.1kR; R_0603_1608Metric

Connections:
/BLDC Driver 1/AGND: NT1.1; also elsewhere on the board
/BLDC Driver 2/AGND: NT2.1; also elsewhere on the board
/CS_ENC_M1: J7.6; also elsewhere on the board
/CS_ENC_M2: J10.6; also elsewhere on the board
/MOUT1_M1: J6.1; also elsewhere on the board
/MOUT1_M2: J9.1; also elsewhere on the board
/MOUT2_M1: J6.2; also elsewhere on the board
/MOUT2_M2: J9.2; also elsewhere on the board
/MOUT3_M1: J6.3; also elsewhere on the board
/MOUT3_M2: J9.3; also elsewhere on the board
/SPI_CLK: J7.5, J10.5; also elsewhere on the board
/SPI_MISO: J7.3, J10.3; also elsewhere on the board
/SPI_MOSI: J7.4, J10.4; also elsewhere on the board
/USB_N: D6.2 (A2), J3.A7 (DN1), J3.B7 (DN2); also elsewhere on the board
/USB_P: D8.2 (A2), J3.A6 (DP1), J3.B6 (DP2); also elsewhere on the board
/USB_UART_N: D5.2 (A2), J2.A7 (DN1), J2.B7 (DN2); also elsewhere on the board
/USB_UART_P: D7.2 (A2), J2.A6 (DP1), J2.B6 (DP2); also elsewhere on the board
GND: D1.1 (A1), D2.1 (A1), D3.1 (A1), D4.1 (A1), D5.1 (A1), D6.1 (A1), D7.1 (A1), D8.1 (A1), J1.2, J2.A1/B12 (GND), J2.B1/A12 (GND), J3.A1/B12 (GND), J3.B1/A12 (GND), J4.2, J5.2, J7.1, J8.2, J10.1, NT1.2, NT2.2, R1.2, R2.2, R3.2, R4.2; also elsewhere on the board
unnamed: F1.2, J1.1
unnamed: J2.A5 (CC1), R1.1
unnamed: J2.B5 (CC2), R2.1
unnamed: J3.A5 (CC1), R3.1
unnamed: J3.B5 (CC2), R4.1
unnamed: F2.2, J4.1
VBUS_5V_1: D2.2 (A2), J2.A4/B9 (VBUS), J2.B4/A9 (VBUS); also elsewhere on the board
VBUS_5V_2: D3.2 (A2), J3.A4/B9 (VBUS), J3.B4/A9 (VBUS); also elsewhere on the board
VIN_5V: D4.2 (A2), F2.1; also elsewhere on the board
VIN_12V: D1.2 (A2), F1.1; also elsewhere on the board
VOUT_5V: J7.2, J8.1, J10.2; also elsewhere on the board
VOUT_12V: J5.1; also elsewhere on the board

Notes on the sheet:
Power
Outputs
Inputs
Encoder
Subsystems
Driver
Motor 2
Motor 1

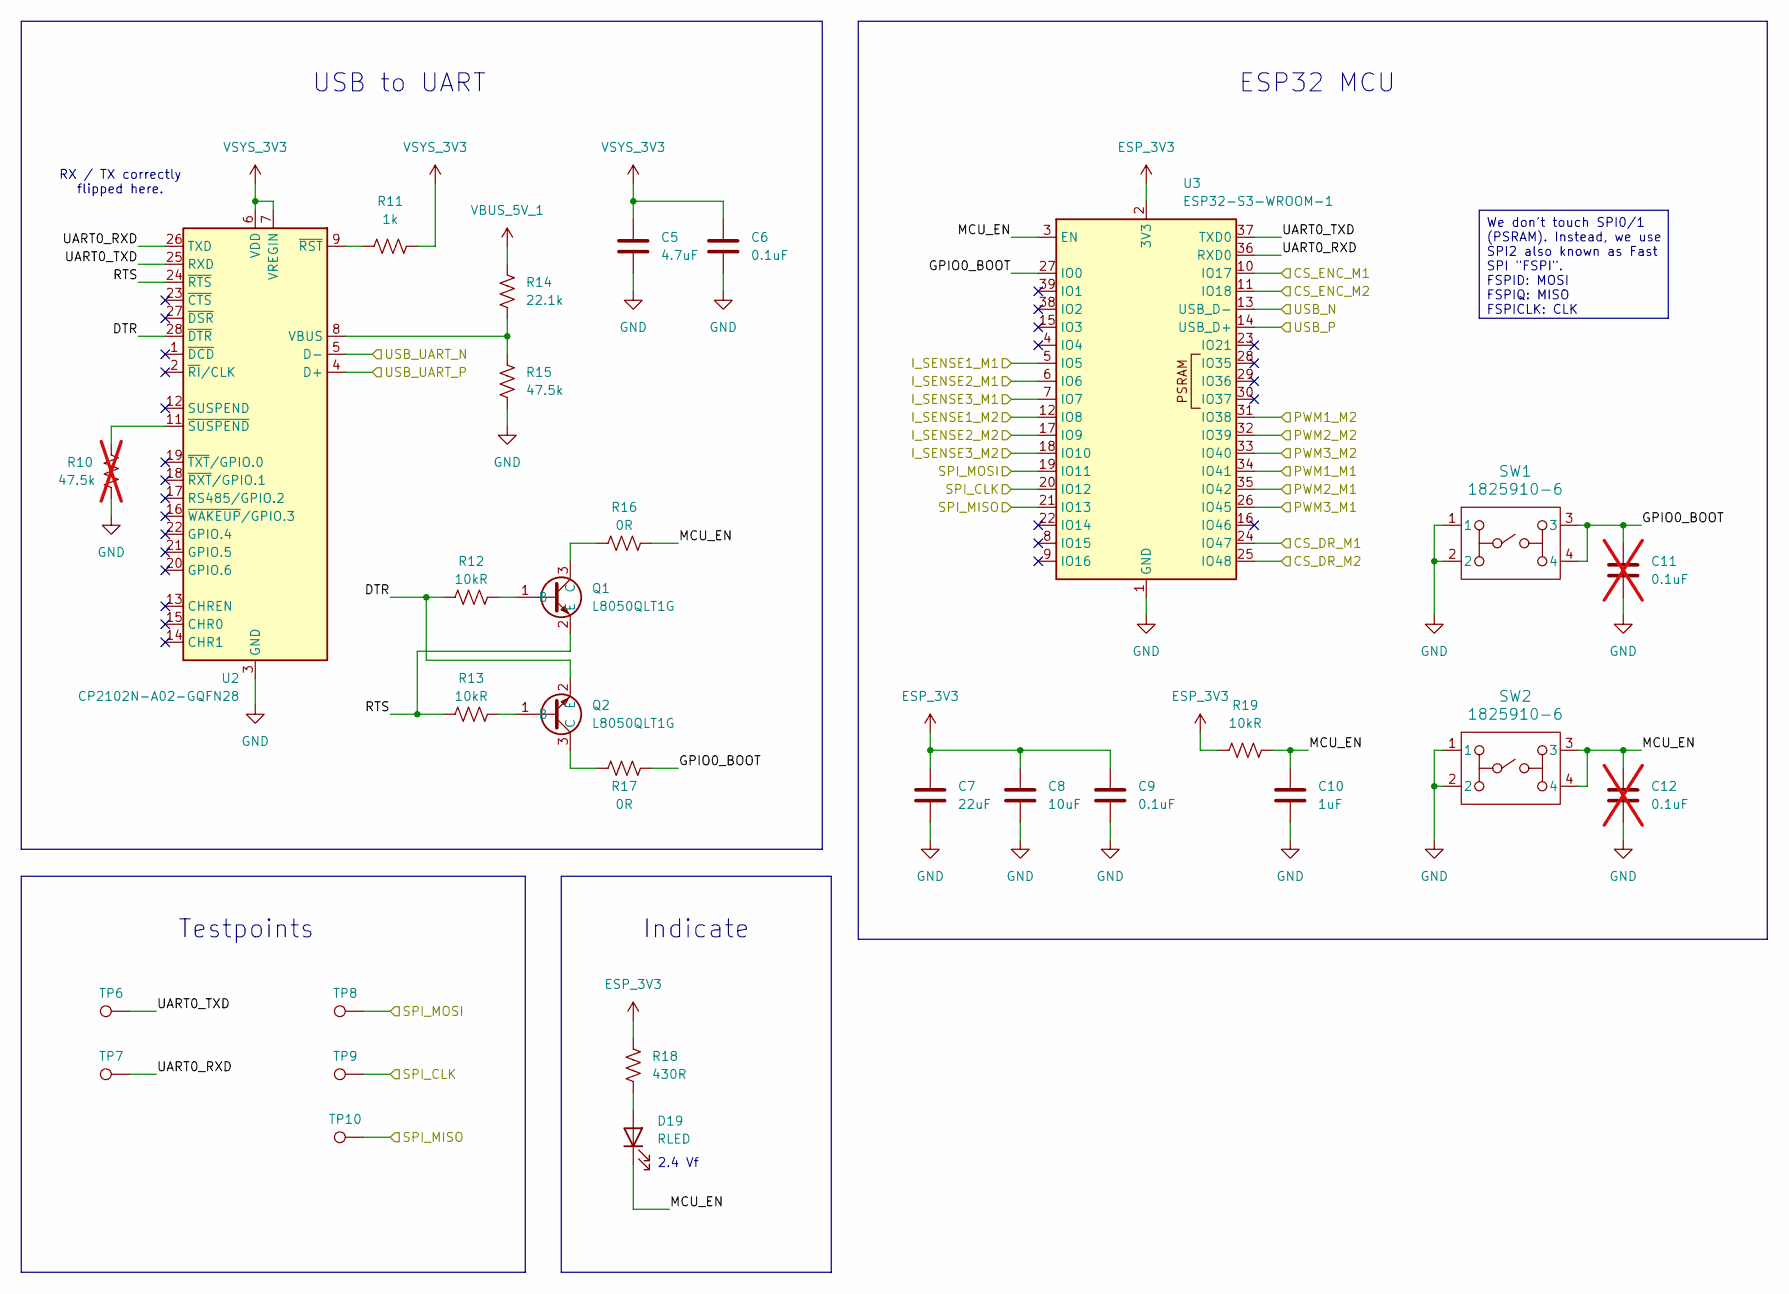
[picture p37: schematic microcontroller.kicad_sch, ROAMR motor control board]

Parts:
C5: 4.7uF; C_0603_1608Metric
C6, C9: 0.1uF; C_0603_1608Metric
C7: 22uF; C_0603_1608Metric
C8: 10uF; C_0603_1608Metric
C10: 1uF; C_0603_1608Metric
C11, C12: 0.1uF; C_0603_1608Metric; not fitted
D19: RLED; LEDC1608X70N; Manufacturer_Part_Number KT-0603R
Q1, Q2: L8050QLT1G; Manufacturer_Part_Number L8050QLT1G
R10: 47.5k; R_0603_1608Metric; not fitted
R11: 1k; R_0603_1608Metric
R12, R13, R19: 10kR; R_0603_1608Metric
R14: 22.1k; R_0603_1608Metric
R15: 47.5k; R_0603_1608Metric
R16, R17: 0R; R_0603_1608Metric
R18: 430R; R_0603_1608Metric
SW1, SW2: 1825910-6; SW4_1825910-B_TEC; Manufacturer_Part_Number 1825910-6
TP6, TP7, TP8, TP9, TP10: TestPoint; TestPoint_Pad_D1.5mm
U2: CP2102N-A02-GQFN28; QFN-28-1EP_5x5mm_P0.5mm_EP3.35x3.35mm; Manufacturer_Part_Number CP2102N-A02-GQFN28
U3: ESP32-S3-WROOM-1; Manufacturer_Part_Number ESP32-S3-WROOM-1

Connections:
/CS_DR_M1: U3.24 (IO47); also elsewhere on the board
/CS_DR_M2: U3.25 (IO48); also elsewhere on the board
/CS_ENC_M1: U3.10 (IO17); also elsewhere on the board
/CS_ENC_M2: U3.11 (IO18); also elsewhere on the board
/ISENSE1_M1: U3.5 (IO5); also elsewhere on the board
/ISENSE1_M2: U3.12 (IO8); also elsewhere on the board
/ISENSE2_M1: U3.6 (IO6); also elsewhere on the board
/ISENSE2_M2: U3.17 (IO9); also elsewhere on the board
/ISENSE3_M1: U3.7 (IO7); also elsewhere on the board
/ISENSE3_M2: U3.18 (IO10); also elsewhere on the board
/Microcontroller/DTR: Q2.2 (E), R12.1, U2.28 (~DTR)
/Microcontroller/GPIO0_BOOT: C11.1, R17.2, SW1.3, SW1.4, U3.27 (IO0)
/Microcontroller/MCU_EN: C10.1, C12.1, D19.1 (K), R16.2, R19.2, SW2.3, SW2.4, U3.3 (EN)
/Microcontroller/RTS: Q1.2 (E), R13.1, U2.24 (~RTS)
/Microcontroller/UART0_RXD: TP7.1, U2.26 (TXD), U3.36 (RXD0)
/Microcontroller/UART0_TXD: TP6.1, U2.25 (RXD), U3.37 (TXD0)
/PWM1_M1: U3.34 (IO41); also elsewhere on the board
/PWM1_M2: U3.31 (IO38); also elsewhere on the board
/PWM2_M1: U3.35 (IO42); also elsewhere on the board
/PWM2_M2: U3.32 (IO39); also elsewhere on the board
/PWM3_M1: U3.26 (IO45); also elsewhere on the board
/PWM3_M2: U3.33 (IO40); also elsewhere on the board
/SPI_CLK: TP9.1, U3.20 (IO12); also elsewhere on the board
/SPI_MISO: TP10.1, U3.21 (IO13); also elsewhere on the board
/SPI_MOSI: TP8.1, U3.19 (IO11); also elsewhere on the board
/USB_N: U3.13 (USB_D-); also elsewhere on the board
/USB_P: U3.14 (USB_D+); also elsewhere on the board
/USB_UART_N: U2.5 (D-); also elsewhere on the board
/USB_UART_P: U2.4 (D+); also elsewhere on the board
ESP_3V3: C7.1, C8.1, C9.1, R18.2, R19.1, U3.2 (3V3); also elsewhere on the board
GND: C5.2, C6.2, C7.2, C8.2, C9.2, C10.2, C11.2, C12.2, R10.1, R15.1, SW1.1, SW1.2, SW2.1, SW2.2, U2.3 (GND), U2.29 (GND), U3.1 (GND), U3.40 (GND), U3.41 (GND); also elsewhere on the board
unnamed: D19.2 (A), R18.1
unnamed: Q1.1 (B), R12.2
unnamed: Q1.3 (C), R16.1
unnamed: Q2.1 (B), R13.2
unnamed: Q2.3 (C), R17.1
unnamed: R14.1, R15.2, U2.8 (VBUS)
unnamed: R11.1, U2.9 (~RST)
unnamed: R10.2, U2.11 (~SUSPEND)
VBUS_5V_1: R14.2; also elsewhere on the board
VSYS_3V3: C5.1, C6.1, R11.2, U2.6 (VDD), U2.7 (VREGIN); also elsewhere on the board

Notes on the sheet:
2.4 Vf
Indicate
RX / TX correctly flipped here.
USB to UART
ESP32 MCU
Testpoints
We don't touch SPI0/1 (PSRAM). Instead, we use SPI2 also known as Fast SPI "FSPI". FSPID: MOSI FSPIQ: MISO FSPICLK: CLK

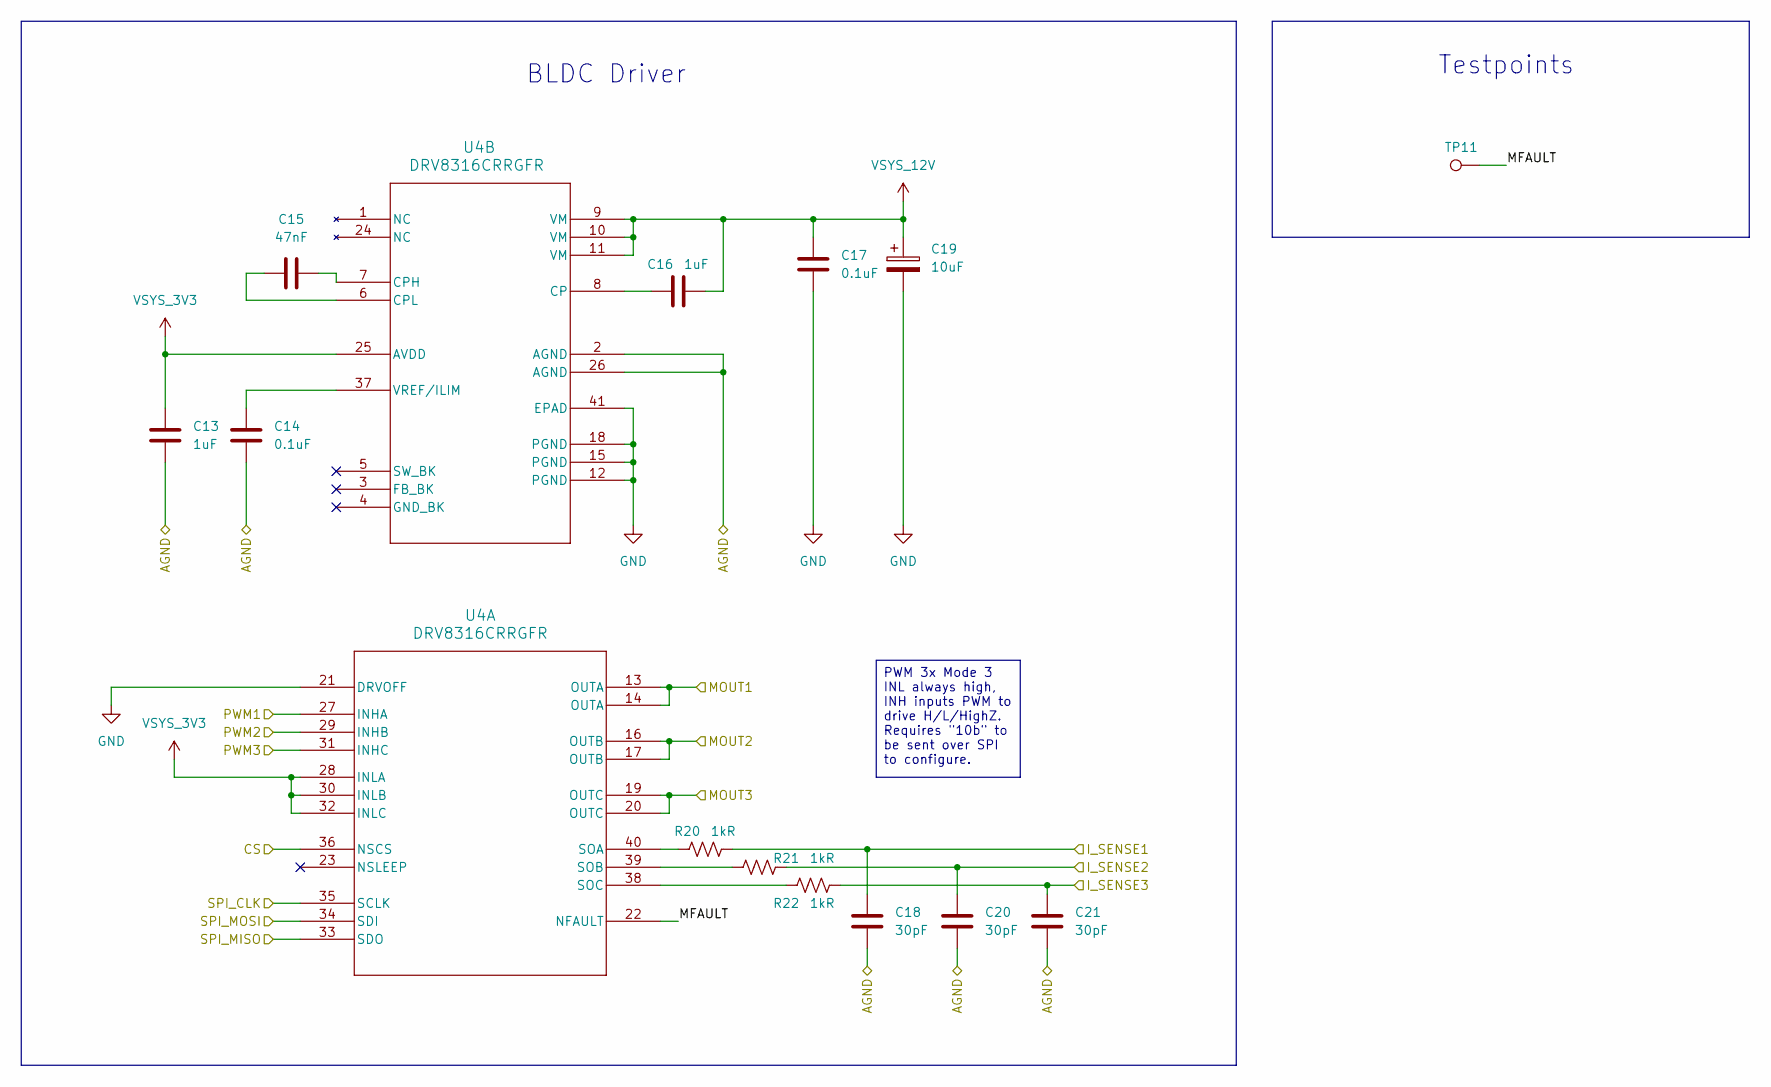
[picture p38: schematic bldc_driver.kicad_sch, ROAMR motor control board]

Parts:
C13, C16: 1uF; C_0603_1608Metric
C14, C17: 0.1uF; C_0603_1608Metric
C15: 47nF; C_0603_1608Metric
C18, C20, C21: 30pF; C_0603_1608Metric
C19: 10uF; RVT1E100M0405
R20, R21, R22: 1kR; R_0603_1608Metric
TP11: TestPoint; TestPoint_Pad_D1.5mm
U4: DRV8316CRRGFR; VQFN40_RGF_TEX; Manufacturer_Part_Number DRV8316CRRGFR

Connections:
/BLDC Driver 1/AGND: C13.2, C14.2, C18.2, C20.2, C21.2, U4.2 (AGND), U4.26 (AGND); also elsewhere on the board
/BLDC Driver 1/MFAULT: TP11.1, U4.22 (NFAULT)
/CS_DR_M1: U4.36 (NSCS); also elsewhere on the board
/ISENSE1_M1: C18.1, R20.2; also elsewhere on the board
/ISENSE2_M1: C20.1, R21.2; also elsewhere on the board
/ISENSE3_M1: C21.1, R22.2; also elsewhere on the board
/MOUT1_M1: U4.13 (OUTA), U4.14 (OUTA); also elsewhere on the board
/MOUT2_M1: U4.16 (OUTB), U4.17 (OUTB); also elsewhere on the board
/MOUT3_M1: U4.19 (OUTC), U4.20 (OUTC); also elsewhere on the board
/PWM1_M1: U4.27 (INHA); also elsewhere on the board
/PWM2_M1: U4.29 (INHB); also elsewhere on the board
/PWM3_M1: U4.31 (INHC); also elsewhere on the board
/SPI_CLK: U4.35 (SCLK); also elsewhere on the board
/SPI_MISO: U4.33 (SDO); also elsewhere on the board
/SPI_MOSI: U4.34 (SDI); also elsewhere on the board
GND: C17.2, C19.2, U4.12 (PGND), U4.15 (PGND), U4.18 (PGND), U4.21 (DRVOFF), U4.41 (EPAD); also elsewhere on the board
unnamed: R20.1, U4.40 (SOA)
unnamed: R21.1, U4.39 (SOB)
unnamed: R22.1, U4.38 (SOC)
unnamed: C16.1, U4.8 (CP)
unnamed: C15.2, U4.7 (CPH)
unnamed: C15.1, U4.6 (CPL)
unnamed: C14.1, U4.37 (VREF/ILIM)
VSYS_3V3: C13.1, U4.25 (AVDD), U4.28 (INLA), U4.30 (INLB), U4.32 (INLC); also elsewhere on the board
VSYS_12V: C16.2, C17.1, C19.1, U4.9 (VM), U4.10 (VM), U4.11 (VM); also elsewhere on the board

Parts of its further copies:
C22, C25: 1uF; C_0603_1608Metric
C23, C26: 0.1uF; C_0603_1608Metric
C24: 47nF; C_0603_1608Metric
C27, C29, C30: 30pF; C_0603_1608Metric
C28: 10uF; RVT1E100M0405
R23, R24, R25: 1kR; R_0603_1608Metric
TP12: TestPoint; TestPoint_Pad_D1.5mm
U5: DRV8316CRRGFR; VQFN40_RGF_TEX; Manufacturer_Part_Number DRV8316CRRGFR

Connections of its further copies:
/BLDC Driver 2/AGND: C22.2, C23.2, C27.2, C29.2, C30.2, U5.2 (AGND), U5.26 (AGND); also elsewhere on the board
/BLDC Driver 2/MFAULT: TP12.1, U5.22 (NFAULT)
/CS_DR_M2: U5.36 (NSCS); also elsewhere on the board
/ISENSE1_M2: C27.1, R23.2; also elsewhere on the board
/ISENSE2_M2: C29.1, R24.2; also elsewhere on the board
/ISENSE3_M2: C30.1, R25.2; also elsewhere on the board
/MOUT1_M2: U5.13 (OUTA), U5.14 (OUTA); also elsewhere on the board
/MOUT2_M2: U5.16 (OUTB), U5.17 (OUTB); also elsewhere on the board
/MOUT3_M2: U5.19 (OUTC), U5.20 (OUTC); also elsewhere on the board
/PWM1_M2: U5.27 (INHA); also elsewhere on the board
/PWM2_M2: U5.29 (INHB); also elsewhere on the board
/PWM3_M2: U5.31 (INHC); also elsewhere on the board
/SPI_CLK: U5.35 (SCLK); also elsewhere on the board
/SPI_MISO: U5.33 (SDO); also elsewhere on the board
/SPI_MOSI: U5.34 (SDI); also elsewhere on the board
GND: C26.2, C28.2, U5.12 (PGND), U5.15 (PGND), U5.18 (PGND), U5.21 (DRVOFF), U5.41 (EPAD); also elsewhere on the board
unnamed: R23.1, U5.40 (SOA)
unnamed: R24.1, U5.39 (SOB)
unnamed: R25.1, U5.38 (SOC)
unnamed: C25.1, U5.8 (CP)
unnamed: C24.2, U5.7 (CPH)
unnamed: C24.1, U5.6 (CPL)
unnamed: C23.1, U5.37 (VREF/ILIM)
VSYS_3V3: C22.1, U5.25 (AVDD), U5.28 (INLA), U5.30 (INLB), U5.32 (INLC); also elsewhere on the board
VSYS_12V: C25.2, C26.1, C28.1, U5.9 (VM), U5.10 (VM), U5.11 (VM); also elsewhere on the board

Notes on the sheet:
Testpoints
BLDC Driver
PWM 3x Mode 3 INL always high, INH inputs PWM to drive H/L/HighZ. Requires "10b" to be sent over SPI to configure.

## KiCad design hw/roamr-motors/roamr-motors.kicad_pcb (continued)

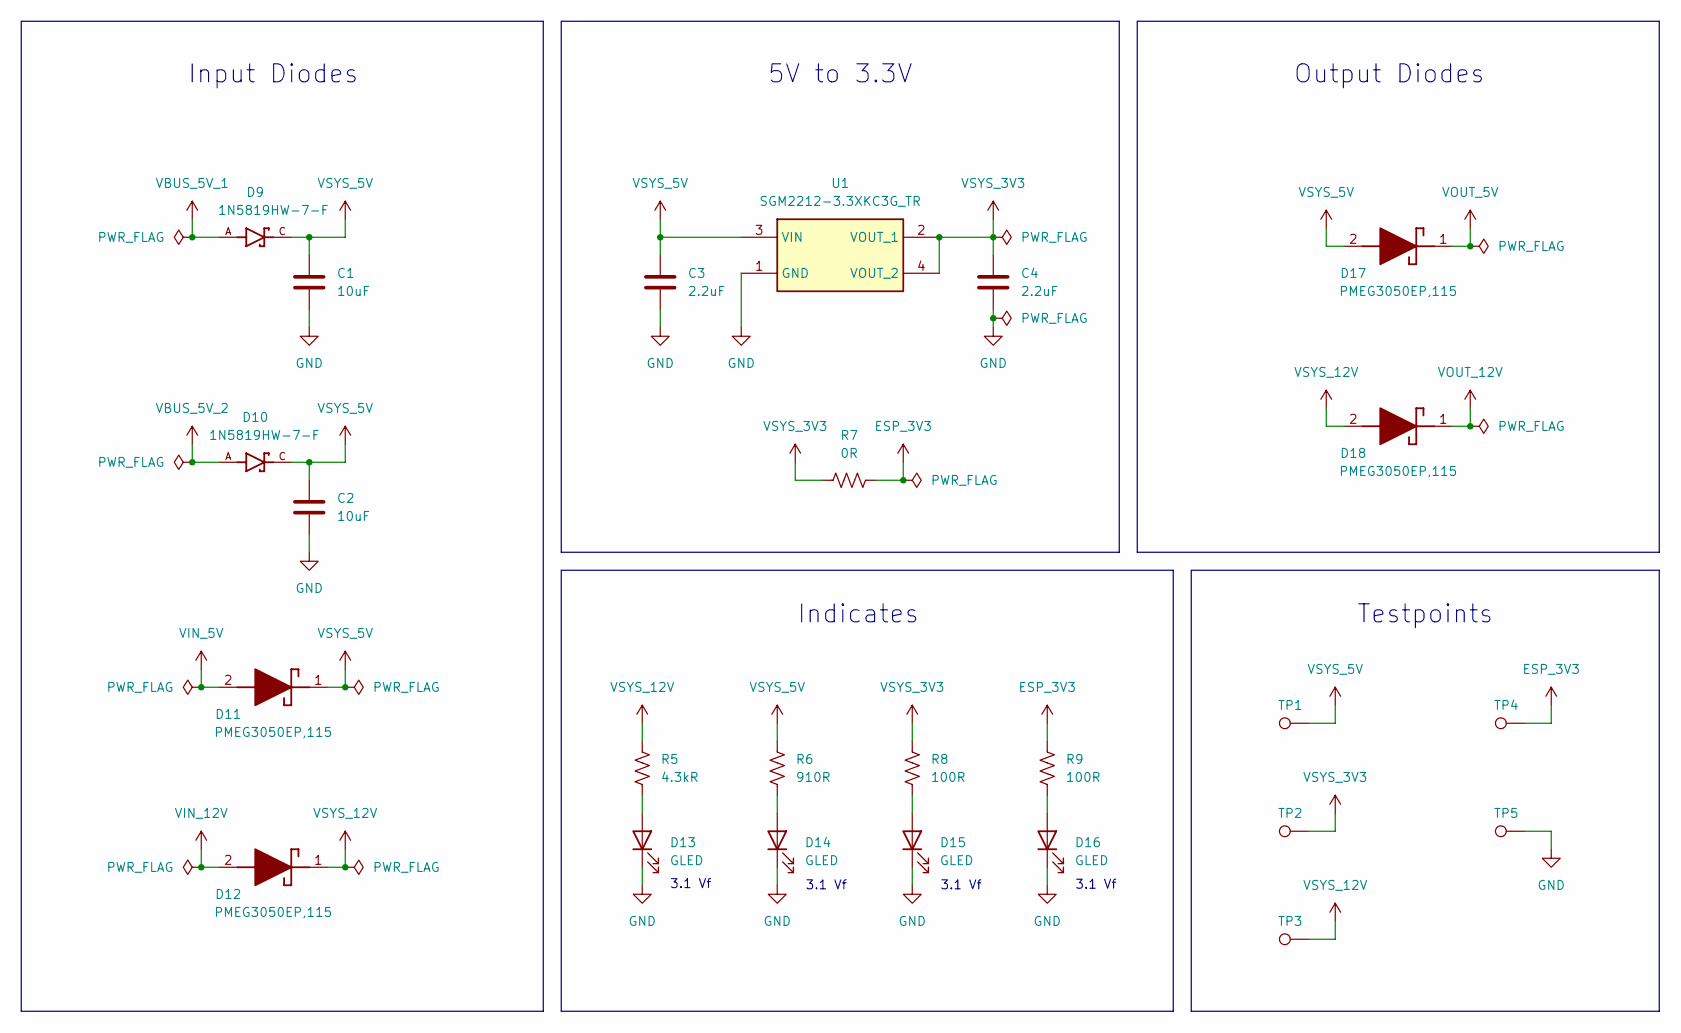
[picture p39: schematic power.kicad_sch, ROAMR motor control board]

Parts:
C1, C2: 10uF; C_0603_1608Metric
C3, C4: 2.2uF; C_0603_1608Metric
D9, D10: 1N5819HW-7-F; SOD3715X145N; PARTREV 18-2
D11, D12, D17, D18: PMEG3050EP,115; PMEG3050EP115; Mouser Part Number 771-PMEG3050EP115
D13, D14, D15, D16: GLED; LEDC1608X70N; Manufacturer_Part_Number KT-0603G
R5: 4.3kR; R_0603_1608Metric
R6: 910R; R_0603_1608Metric
R7: 0R; R_0603_1608Metric
R8, R9: 100R; R_0603_1608Metric
TP1, TP2, TP3, TP4: TestPoint; TestPoint_Pad_D1.5mm
TP5: TestPoint; TestPoint_Keystone_5005-5009_Compact; Manufacturer_Part_Number 5005-5009
U1: SGM2212-3.3XKC3G_TR; SOT230P700X180-4N; Manufacturer_Part_Number SGM2212-3.3XKC3G/TR

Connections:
ESP_3V3: R7.2, R9.1, TP4.1; also elsewhere on the board
GND: C1.2, C2.2, C3.2, C4.2, D13.1 (K), D14.1 (K), D15.1 (K), D16.1 (K), TP5.1, U1.1 (GND); also elsewhere on the board
unnamed: D13.2 (A), R5.2
unnamed: D14.2 (A), R6.2
unnamed: D15.2 (A), R8.2
unnamed: D16.2 (A), R9.2
VBUS_5V_1: D9.A; also elsewhere on the board
VBUS_5V_2: D10.A; also elsewhere on the board
VIN_5V: D11.2 (A); also elsewhere on the board
VIN_12V: D12.2 (A); also elsewhere on the board
VOUT_5V: D17.1 (K); also elsewhere on the board
VOUT_12V: D18.1 (K); also elsewhere on the board
VSYS_3V3: C4.1, R7.1, R8.1, TP2.1, U1.2 (VOUT_1), U1.4 (VOUT_2); also elsewhere on the board
VSYS_5V: C1.1, C2.1, C3.1, D9.C, D10.C, D11.1 (K), D17.2 (A), R6.1, TP1.1, U1.3 (VIN)
VSYS_12V: D12.1 (K), D18.2 (A), R5.1, TP3.1; also elsewhere on the board

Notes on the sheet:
Input Diodes
3.1 Vf
Output Diodes
Testpoints
5V to 3.3V
Indicates

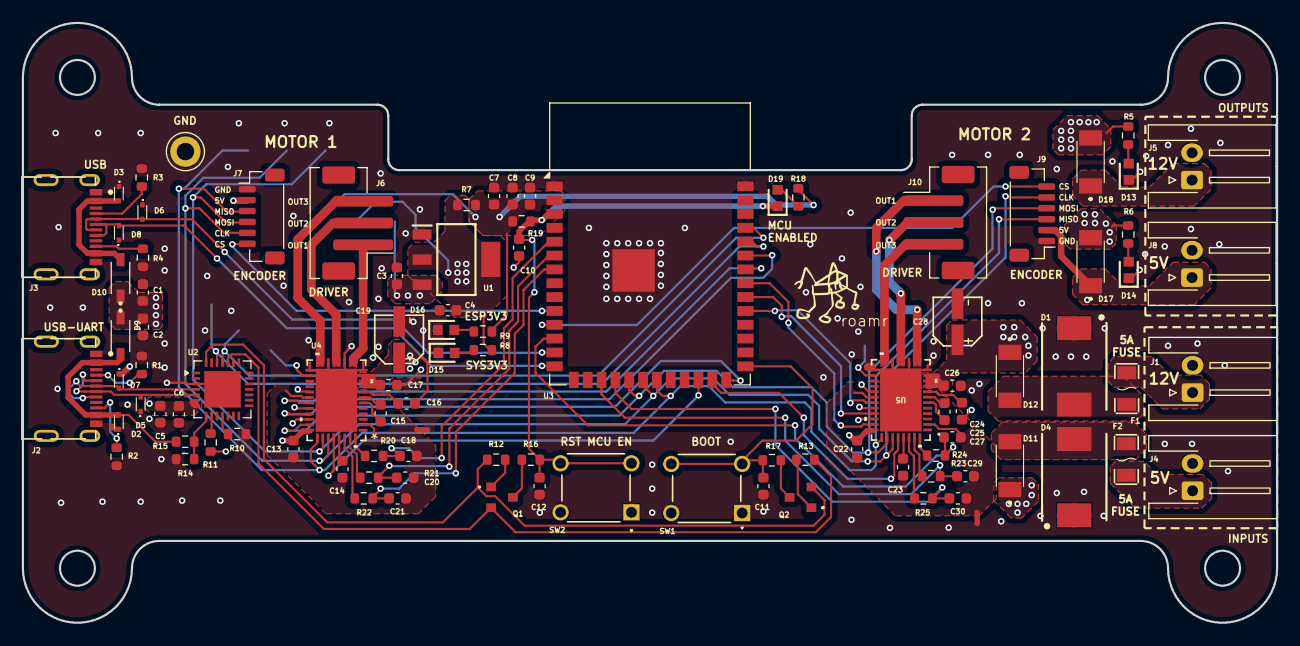
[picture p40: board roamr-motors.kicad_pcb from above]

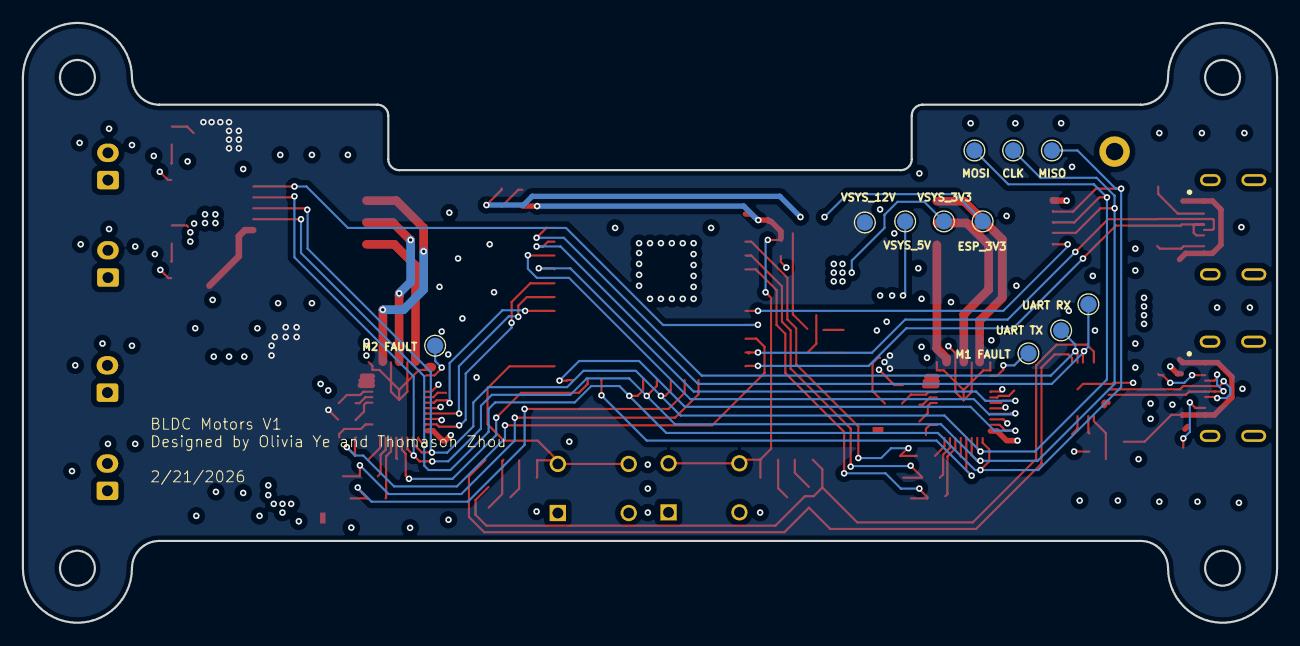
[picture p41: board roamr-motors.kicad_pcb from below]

Board: 4 copper layers, 115.0 x 55.0 mm, 109 parts (11 on the bottom side), 82 nets.

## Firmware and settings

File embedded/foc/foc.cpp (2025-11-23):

#include <Arduino.h>
#include <SPI.h>
// #include "driver/gpio.h"
// #include "driver/spi_master.h"


#include <SimpleFOC.h>
#include <SimpleFOCDrivers.h>
#include "encoders/as5048a/MagneticSensorAS5048A.h"

#define PIN_MOSI  1
#define PIN_SCLK  2
#define PIN_MISO  3
#define PIN_CS    4

constexpr int PIN_DRIVER_1 = 5;
constexpr int PIN_DRIVER_2 = 20;
constexpr int PIN_DRIVER_3 = 32;
constexpr int PIN_EN = 33;


// spi_device_handle_t spi;

// void spi_init_as5048a()
// {
//   spi_bus_config_t buscfg = {};    // zero-init all fields
//   buscfg.miso_io_num     = PIN_MISO;
//   buscfg.mosi_io_num     = PIN_MOSI;
//   buscfg.sclk_io_num     = PIN_CLK;
//   buscfg.quadwp_io_num   = -1;
//   buscfg.quadhd_io_num   = -1;
//   buscfg.max_transfer_sz = 32;

//   spi_device_interface_config_t devcfg = {};  // zero-init all fields
//   devcfg.clock_speed_hz = 2 * 1000 * 1000;  // 2 MHz
//   devcfg.mode           = 1;                // SPI mode 1
//   devcfg.spics_io_num   = PIN_CS;
//   devcfg.queue_size     = 1;

//   spi_bus_initialize(SPI2_HOST, &buscfg, SPI_DMA_CH_AUTO);
//   spi_bus_add_device(SPI2_HOST, &devcfg, &spi);
// }

MagneticSensorAS5048A sensor1(PIN_CS);
BLDCDriver3PWM driver1(PIN_DRIVER_1, PIN_DRIVER_2, PIN_DRIVER_3, PIN_EN);
BLDCMotor motor1(7);
Commander command = Commander(Serial);
void doMotor(char* cmd) {command.motor(&motor1, cmd);}

void setup() {
  Serial.begin(115200);
  SPI.begin(PIN_SCLK, PIN_MISO, PIN_MOSI);

  sensor1.init();
  motor1.linkSensor(&sensor1);
  
  driver1.voltage_power_supply = 12;
  driver1.voltage_limit = 12;
  if (!driver1.init()){
    Serial.println("Driver failed");
    return;
  }
  motor1.linkDriver(&driver1);

  motor1.torque_controller = TorqueControlType::voltage;
  motor1.controller = MotionControlType::torque;

  motor1.voltage_sensor_align = 12.0f;
  if (!motor1.init()){
    Serial.println("Motor failed");
    return;
  }

  if(!motor1.initFOC()){
    Serial.println("FOC failed");
    return;
  }

  motor1.target = 0.5; // Nm  

  command.add('M', doMotor, "Motor");
  Serial.println(F("Motor ready."));
  Serial.println(F("Set the target with command M:"));

}

void loop() {
  motor1.loopFOC();
  motor1.move();
  command.run();
}

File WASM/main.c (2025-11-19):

#include <stdio.h>
#include <stdlib.h>

int main() {
    // Attempt to allocate 10MB to demonstrate
    void* big_chunk = malloc(1 * 1024 * 1024); 
    if (big_chunk) {
        printf("Memory allocation successful.\n");
        free(big_chunk);
    } else {
        printf("Memory allocation failed.\n");
    }
    return 0;
}

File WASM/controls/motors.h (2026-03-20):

#pragma once

#include <algorithm>
#include <cmath>
#include <cstdint>
#include <limits>
#include <thread>
#include <chrono>

#include "core/wasm_utils.h"
#include "core/math_utils.h"
#include "sensors/wheel_odometry.h"

namespace controls{
    // Desired motor output in percentage of full scale (-100 to 100)
    // hold_ms lets the host decide how long to keep this command alive.
    struct MotorCommand {
        int32_t left_percent;   // left wheel, -100..100
        int32_t right_percent;  // right wheel, -100..100
        int32_t hold_ms;        // command validity in milliseconds
    };

    WASM_IMPORT("host", "write_motors") void write_motors(const MotorCommand *cmd);

    struct TwistCommand {
        double v_mps;           // body-frame linear velocity (m/s)
        double omega_rad_s;     // body-frame yaw rate (rad/s)
        int32_t hold_ms;        // command validity in milliseconds
    };

    constexpr double kMaxLinearSpeedMps = 0.3;
    constexpr double kMaxAngularSpeedRadPerSec = core::pi;

    struct WheelSpeedSetpoint {
        double left_mps;
        double right_mps;
    };

    struct WheelCommandBandConfig {
        // Keep nonzero wheel commands in this range.
        double min_moving_percent = 14.0;
        double max_moving_percent = 18.0;
        // If desired wheel speed is below this threshold, command a full stop.
        double stop_speed_threshold_mps = 0.01;
        // PI correction is intentionally small; feedforward does most of the work.
        double max_trim_percent = 3.0;
        // Maximum wheel speed expected while staying inside moving percent band.
        double max_wheel_speed_for_band_mps = 0.16;
    };

    struct TwistCommandCalibrationConfig {
        // Scales (v, omega) before converting to wheel speed setpoints.
        // Defaults tuned for uninterrupted odom updates from a single consumer.
        double linear_scale = 0.25;
        double angular_scale = 1.1;
    };

    struct WheelSpeedControllerConfig {
        // PI trim around a feedforward operating band.
        double kp_percent_per_mps = 20.0;
        double ki_percent_per_mps_s = 3.0;
        double integral_limit_percent = 6.0;
        WheelCommandBandConfig band = {};
        TwistCommandCalibrationConfig twist_calibration = {};
    };

    struct TurnInPlaceConfig {
        // Outer-loop yaw controller that commands angular velocity from yaw error.
        double kp_omega_per_rad = 2.0;
        double max_omega_rad_s = 0.9 * kMaxAngularSpeedRadPerSec;
        double min_omega_rad_s = 0.2;
        double yaw_tolerance_rad = 3.0 * core::pi / 180.0;
    };

    inline TwistCommand clamp_twist_command(const TwistCommand& cmd) {
        return TwistCommand{
            std::clamp(cmd.v_mps, -kMaxLinearSpeedMps, kMaxLinearSpeedMps),
            std::clamp(cmd.omega_rad_s, -kMaxAngularSpeedRadPerSec, kMaxAngularSpeedRadPerSec),
            cmd.hold_ms};
    }

    inline WheelSpeedSetpoint wheel_speed_setpoint_from_twist(const TwistCommand& cmd) {
        const TwistCommand clamped = clamp_twist_command(cmd);
        const double half_wheel_base = 0.5 * sensors::kWheelBaseMeters;
        return WheelSpeedSetpoint{
            clamped.v_mps - (clamped.omega_rad_s * half_wheel_base),
            clamped.v_mps + (clamped.omega_rad_s * half_wheel_base)};
    }

    inline TwistCommand apply_twist_calibration(
        const TwistCommand& cmd,
        const TwistCommandCalibrationConfig& cfg) {
        const double linear_scale = std::max(0.0, cfg.linear_scale);
        const double angular_scale = std::max(0.0, cfg.angular_scale);
        return TwistCommand{
            cmd.v_mps * linear_scale,
            cmd.omega_rad_s * angular_scale,
            cmd.hold_ms};
    }

    inline WheelSpeedSetpoint clamp_wheel_speed_setpoint_to_band(
        const WheelSpeedSetpoint& desired,
        double max_abs_wheel_speed_mps) {
        const double max_abs_speed = std::max(0.0, max_abs_wheel_speed_mps);
        if (max_abs_speed <= 0.0) {
            return WheelSpeedSetpoint{0.0, 0.0};
        }
        const double peak = std::max(std::abs(desired.left_mps), std::abs(desired.right_mps));
        if (peak <= max_abs_speed || peak <= 1e-9) {
            return desired;
        }
        const double scale = max_abs_speed / peak;
        return WheelSpeedSetpoint{desired.left_mps * scale, desired.right_mps * scale};
    }

    class WheelSpeedPercentController {
    public:
        explicit WheelSpeedPercentController(const WheelSpeedControllerConfig& cfg = {})
            : cfg_(cfg) {}

        void reset() {
            left_i_term_percent_ = 0.0;
            right_i_term_percent_ = 0.0;
        }

        void set_config(const WheelSpeedControllerConfig& cfg) {
            cfg_ = cfg;
            reset();
        }

        const WheelSpeedControllerConfig& config() const { return cfg_; }

        MotorCommand compute(
            const WheelSpeedSetpoint& desired,
            const sensors::WheelSpeedMetersPerSec& measured,
            int hold_ms) {
            const double left_pct = compute_wheel_percent(
                desired.left_mps,
                measured.left,
                measured.dt_seconds,
                &left_i_term_percent_);
            const double right_pct = compute_wheel_percent(
                desired.right_mps,
                measured.right,
                measured.dt_seconds,
                &right_i_term_percent_);

            return MotorCommand{
                clamp_percent(round_to_i32(left_pct)),
                clamp_percent(round_to_i32(right_pct)),
                clamp_nonnegative(hold_ms)};
        }

    private:
        double compute_wheel_percent(
            double desired_mps,
            double measured_mps,
            double dt_seconds,
            double* i_term_percent) const {
            if (!i_term_percent) {
                return 0.0;
            }

            const double desired_abs = std::abs(desired_mps);
            const double stop_threshold = std::max(0.0, cfg_.band.stop_speed_threshold_mps);
            if (desired_abs <= stop_threshold) {
                *i_term_percent = 0.0;
                return 0.0;
            }

            const double error = desired_mps - measured_mps;
            const double i_term_candidate = integrate_i_term(*i_term_percent, error, dt_seconds);
            const double p_term = cfg_.kp_percent_per_mps * error;
            const double trim_limit = std::max(0.0, cfg_.band.max_trim_percent);
            const double trim_unclamped = p_term + i_term_candidate;
            const double trim = clamp_percent_double(trim_unclamped, trim_limit);

            const double ff_abs = feedforward_percent_for_speed(desired_abs);
            const double raw_cmd = std::copysign(ff_abs, desired_mps) + trim;
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

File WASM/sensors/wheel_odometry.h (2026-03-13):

#pragma once

#include <cmath>
#include <cstdint>

#include "core/pose/se2.h"
#include "core/wasm_utils.h"

namespace sensors {

struct WheelOdometryData {
  double timestamp;
  int32_t seq;
  int32_t dl_ticks;
  int32_t dr_ticks;
  int32_t sample_period_ms;
};

WASM_IMPORT("host", "read_wheel_odometry")
void read_wheel_odometry(WheelOdometryData *data);

constexpr double kWheelTicksPerRev = 16384.0; // 2**(14 bit)
constexpr double kWheelRadiusMeters = 0.025;
constexpr double kWheelBaseMeters = 0.155;
constexpr double kTwoPi = 6.28318530717958647692;

struct WheelDeltaMeters {
  double left;
  double right;
};

struct WheelSpeedMetersPerSec {
  double left;
  double right;
  double dt_seconds;
};

constexpr double wheel_meters_per_tick() {
  return (kTwoPi * kWheelRadiusMeters) / kWheelTicksPerRev;
}

inline WheelDeltaMeters wheel_delta_meters_from_ticks(const WheelOdometryData& odom) {
  const double meters_per_tick = wheel_meters_per_tick();
  return WheelDeltaMeters{
      static_cast<double>(odom.dl_ticks) * meters_per_tick,
      static_cast<double>(odom.dr_ticks) * meters_per_tick,
  };
}

inline WheelSpeedMetersPerSec wheel_speed_from_odometry(const WheelOdometryData& odom) {
  const WheelDeltaMeters delta = wheel_delta_meters_from_ticks(odom);
  const double dt_seconds = static_cast<double>(odom.sample_period_ms) * 1e-3;
  if (dt_seconds <= 0.0) {
    return WheelSpeedMetersPerSec{0.0, 0.0, 0.0};
  }
  return WheelSpeedMetersPerSec{
      delta.left / dt_seconds,
      delta.right / dt_seconds,
      dt_seconds,
  };
}

inline void integrate_wheel_odometry(
    const WheelOdometryData& odom,
    core::PoseSE2d& pose) {
  const WheelDeltaMeters delta = wheel_delta_meters_from_ticks(odom);
  const double dl = delta.left;
  const double dr = delta.right;

  const double ds = 0.5 * (dl + dr);
  const double dtheta = (dr - dl) / kWheelBaseMeters;
  const double heading_mid = pose.theta + (0.5 * dtheta);

  pose.x += ds * std::cos(heading_mid);
  pose.y += ds * std::sin(heading_mid);
  pose.theta += dtheta;
}

inline void integrate_wheel_odometry(
    const WheelOdometryData& odom,
    double heading,
    core::PoseSE2d& pose) {
  const WheelDeltaMeters delta = wheel_delta_meters_from_ticks(odom);
  const double ds = 0.5 * (delta.left + delta.right);

  // In FLU, positive wheel travel should move the body forward along +x.
  pose.x += ds * std::cos(heading);
  pose.y += ds * std::sin(heading);
  pose.theta = heading;
}
} // namespace sensors

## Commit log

2025-11-24 Limit rate of logging thread (#12)
2026-01-09 Implement LidarCameraManager
2026-01-09 Remove unneeded print
2026-01-18 Tz/lidar camera (#15)
    * Add AVFoundation code for configuring capture session, todo: callback for updating data
    * Add copy logic with dirty flag
    * Implement LidarCameraManager
    * Remove unneeded print
    * Added depth view along with a visual overhaul of app.
    * Added point cloud view along with websocket page fix
    * Added point cloud size
    * Update data structures
    * Remove duplicates
    * Remove stray var
    ---------
    [lidar_camera.h]
2026-01-22 Added wasm hub to iOS and website (#20)
    * Added wasm viewer/downloader/uploader to web and ios sides. Currently just has user pass login
    * Added new wasm website and integration with ios with working upload and download, only sign in with google sso
2026-02-03 Access lidar camera data in WASM, log to rerun websocket (#18)
2026-02-06 WASM motors (#22)
    * Access lidar camera data in WASM
    * WASM bundle search
    * swift-side multithreading
    * Log 3d points
    * Add rerun logging
    * Add ui update
    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
2026-02-06 camera frame mapping
2026-02-07 filtered yaw from IMU
2026-02-09 Log raw IMU
2026-02-09 Add initial IMU calibration
2026-02-12 Coordinate frames
2026-02-12 Missing rotate by 90 x
    [lidar_camera.h]
2026-02-12 Frames aligned
2026-02-12 IMU and map
2026-02-12 Update IMU calib to block mapping
2026-02-12 Speed up with double lidar buffer
2026-03-01 Add BLE packet for wheel odometry
2026-03-01 wheel encoder
2026-03-02 prefer esp32_c6
2026-03-03 Refactor to use wheel odom rotation as source of truth
2026-03-03 prefer esp32_c6 again
2026-03-03 use wheel odom pose
2026-03-04 goal point and plan (outer pid untested)
2026-03-04 WASM odom mapping (#37)
    * Refactor to use wheel odom rotation as source of truth
    * map with translation trail
    * Use poseSE3d for translation/rotation
    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
2026-03-05 color filtered 3d points pink
2026-03-05 Update ESP32 firmware for S3 board with DRV8316R motor drivers (#42)
    [partitions.csv]
2026-03-16 Power PCB V1 (#19)
    [12v_to_5v.kicad_sch, KT-0603R--3DModel-STEP-269445.STEP, SMLJ13CA-R.stp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]
2026-03-16 BLDC Motors PCB V1 (#17)
    [1N5819HW-7-F.step, B3B-PH-SM4-TB_LF__SN_.stp, CAP-SMD_L4.3-W4.3-H5.3-LS5.1.step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]
2026-03-16 Power PCB V1 - Fixed (#49)
    [35SVPF39M.stp, BSS84PH6327XTSA2.stp, ETQ-P4M3R3YFN.stp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]

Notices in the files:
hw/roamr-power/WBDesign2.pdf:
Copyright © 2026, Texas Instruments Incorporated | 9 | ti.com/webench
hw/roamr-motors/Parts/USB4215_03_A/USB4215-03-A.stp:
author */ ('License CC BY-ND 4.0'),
